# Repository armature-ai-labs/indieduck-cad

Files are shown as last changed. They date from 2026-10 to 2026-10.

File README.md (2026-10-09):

# IndieDuck by Armature AI Labs

A complete **R20 robot CAD study**, with the removable rear colour band integrated into the assembled robot. Adapted from Open Duck Mini and inspired by Pollen Robotics' MicroDuck, with reused XGO geometry identified in [THIRD_PARTY_NOTICES.md](THIRD_PARTY_NOTICES.md).

Armature's changes include compact joint supports, a two-eye face, local head-yaw clearance and a separately printable colour band. This repository contains the mechanical CAD only; runtime and reinforcement learning remain in [indieduck-runtime](https://github.com/armature-ai-labs/indieduck-runtime) and [indieduck-rl](https://github.com/armature-ai-labs/indieduck-rl).

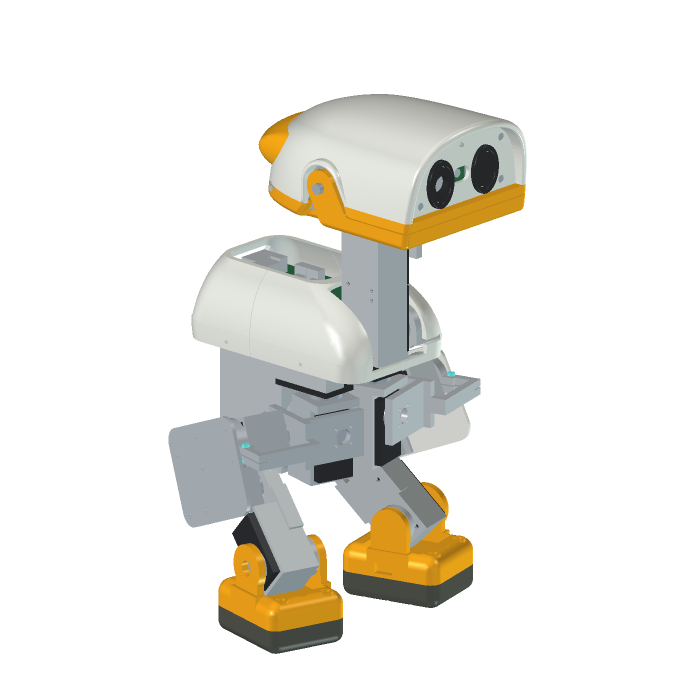
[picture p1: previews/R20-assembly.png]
R20 assembled CAD


## Explore and assemble

Open the [interactive R20 assembly guide](https://armature-ai-labs.github.io/indieduck/) for component selection, exploded views and assembly steps. The [R20 simulator](https://armature-ai-labs.github.io/indieduck-rl/) is a separate physics study. The guide uses the saved CAD assembly; it does not simulate a physical installation process.

The `assembly/` bundle provides revisioned, labelled display meshes and component records generated from this CAD. These are presentation assets, not additional printable parts. Use the native sources and `exports/` for mechanical editing and printing. Steps and hardware envelopes marked provisional require confirmation during the physical build.

## Open the robot

Download and extract the entire release ZIP, then open **`native/robot/IndieDuck_R20_Assembly.FCStd`** in FreeCAD 1.1.4. Keep these four sibling files together so relative links resolve:

| File | Purpose |
|---|---|
| `IndieDuck_R20_Assembly.FCStd` | Complete robot in its saved standing pose, including the mounted band |
| `IndieDuck_R20_Structure.FCStd` | Structural parts, covers, face, feet and retained construction history |
| `IndieDuck_R20_Interfaces.FCStd` | Joint carriers, clamps, retainers and hardware references |
| `IndieDuck_R20_HeadBand.FCStd` | Editable band profiles, attachment features and mounting-hole head shell |

Edit the source documents rather than presentation snapshots. Older feature names such as `R17_HeadPitch` remain stable identifiers inside R20; they do not indicate that an older assembly must be downloaded. Hidden construction objects are retained where they support editing and provenance. They are not additional parts to print.

The assembly's `YawMotion` spreadsheet accepts a plain number in cell B1, for example `-90`, `0` or `90`. This is a head-yaw study control, not a general pose editor or a guarantee of physical travel. Restore `0` for the default saved view.

## Files and colours

- `exports/`: matching R20 STEP and STL files for the 41 current printed-component candidates, plus the assembled STEP. Purchased servos, electronics, bearings and metal fasteners remain assembly references, not printed-component exports.
- `previews/`: actual assembled and inspection CAD views.
- `drawings/`: applicable review drawings. Inherited sheets retain their original revision labels; they are not a complete dimensioned manufacturing drawing set.
- [COMPONENTS.csv](COMPONENTS.csv) maps every current printed component; [MANIFEST.json](MANIFEST.json) and [SHA256SUMS](SHA256SUMS) identify the packaged files and their source objects. Keep native files and exports from the same release together.

Geometry uses **millimetres**. Individual exports retain their native CAD coordinates; they are not arranged on a build plate or sliced. Colour in the CAD is an appearance setting, not a material specification. Use PLA for initial rigid fit tests and TPU 95A for soles and lips. Bambu Studio can prepare printer-specific jobs after orientation, supports, nozzle and material profiles are checked.

Print the rear band separately in any desired colour. Multicolour printing is not required. The band covers the retained head reinforcement and is attached using two internal screws and captive nuts. Remove the head shell for screw access; the nuts load through the band's underside slots. It is tool-removable, not a snap-on accessory.

The **M2×10 screw with a nominal 0.5 mm washer** is a provisional stack, not a confirmed hardware specification. In the centre-line CAD stack it leaves about 0.492 mm screw-tip space; a bare 10 mm screw reaches the blind end. Confirm printed nut fit, screw length, head seating and tool access before tightening. The band is decorative, not a handle or impact bumper.

## Prototype limits

“Complete” means the current robot assembly and its current printed-component CAD are packaged together. CAD reopening, link checks, solid checks and export checks are distinct from physical fit, slicing, strength and motion tests. Read [VERIFICATION.md](VERIFICATION.md) for the exact checks performed on this release.

A band mesh/CAD volume discrepancy and a smaller assembled STEP volume discrepancy remain recorded in [VERIFICATION.md](VERIFICATION.md). Inherited neck-motion collisions remain unresolved. Combined head motion, cable routing, full band-removal travel, printed tolerances, bearing preload, fastener engagement and structural loads require further work. No trained walking, impact resistance or reproducible physical build is claimed by this release.

See [CONTRIBUTING.md](CONTRIBUTING.md) for changes. Source-specific attribution, applicable licences and unresolved redistribution terms are collected in [THIRD_PARTY_NOTICES.md](THIRD_PARTY_NOTICES.md); this mixed-source collection is not covered by a blanket Apache-2.0 grant.

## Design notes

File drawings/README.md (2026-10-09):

# Review drawings

The two PDF/SVG sheets in `inherited-R18/` document the compact neck and structural supports retained unchanged in R20. Their original revision labels are preserved. These are review drawings, not a full dimensioned manufacturing set. Use the R20 native model and component manifest for the current parts.

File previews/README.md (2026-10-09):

# Actual FreeCAD R20 views

Assembly, front, rear and attached-band views show the integrated R20 native assembly. `R20-band-exploded.png` temporarily translates only the band 35 mm rearward to reveal the retained shell reinforcement and mount holes. It illustrates separation, not a validated removal path. Geometry was restored after capture. Colours are appearance settings.

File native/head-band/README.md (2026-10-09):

# R20 removable colour band

The editable source is `../robot/IndieDuck_R20_HeadBand.FCStd`. It is kept beside the complete robot assembly so all external links use sibling paths. Edit `RemovableRearBand` and `HeadShellWithBandMounts` through their retained loft/profile/attachment features. Do not use the hidden construction features as additional printed parts.

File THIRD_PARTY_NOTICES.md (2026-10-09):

# Third-party notices and source attribution

IndieDuck by Armature AI Labs, adapted from Open Duck Mini and inspired by Pollen Robotics' MicroDuck.

Copyright 2026 Armature AI Labs for our engineering modifications. Our independently authored contributions and documentation are offered under Apache-2.0, whose text is included below. This grant does not extend to underlying third-party geometry or replace its source-specific terms. This R20 CAD study combines separately authored structure and interfaces, inherited geometry, and our changes. It is not covered by a single blanket Apache-2.0 grant. The retained upstream texts below apply to their respective material; public availability does not supply any missing upstream permission. No sponsorship, endorsement or trademark rights are asserted.

## Source scope

| Source | Pinned revision | Included or referenced material | Recorded terms |
| --- | --- | --- | --- |
| [Open Duck Mini](https://github.com/apirrone/Open_Duck_Mini) by Antoine Pirrone and contributors | `b23317a485b3cec7d8417f352478778b3475173c` | Retained native source history and adapted covers; Jaime Machuca's BD-X-style body-cover mod and Justin Andrews' Park Head mod are credited below. | Apache-2.0, text retained below. |
| [XGO-Duck hardware](https://github.com/LuwuDynamics/xgoduck_hardware) by Luwu Dynamics and upstream contributors | `8b355c6fc374ff7f2921bf78b4880c2b38c57b07` | Head shell, upper bill, jaw, upper/lower lips and retained support source geometry. R20 adds a separate band and shell mounting holes; earlier IndieDuck revisions changed the face, mounting, jaw support and yaw relief. | No finalized source-specific redistribution grant was established in the inspected snapshot. The snapshot's LICENSING and UPSTREAM texts are retained below. This geometry is not newly labelled Apache-2.0. |
| [MicroDuck / microduck_rl](https://github.com/pollen-robotics/microduck_rl) by Pollen Robotics | model reference `273afe0b31c4ab365b9ff806a927b63ac92b5ddd` | Robot inspiration and numerical joint, stance, foot and roller references. No original Pollen mesh files or policies are directly bundled. XGO's recorded Pollen lineage remains applicable to inherited XGO geometry. | Pinned repository distinguishes Apache-2.0 software from its model terms. Software permission is not asserted as a CAD grant. |
| Radxa ZERO 3W and Pollen RPI Robot HAT | Radxa V1.11 mechanical reference; HAT `78f60f711f519e8b57c4b1ea937bd2bb8249b1d3` | Numerical outline, mounting and component-envelope facts represented as reference shapes. | Original Radxa CAD and the HAT STEP's embedded Raspberry Pi model are not included. |
| Feetech HD-1910-C001 documentation | drawing/specification referenced in the project source register | Numerical servo interfaces and simplified hardware reference envelopes. | Manufacturer documentation is not relabelled as IndieDuck CAD. |

Armature contributions include the HD-1910 structure and interface features, compact joint supports, adapted covers, two-eye face and eye rings, foot studies, the upper-bill yaw clearance, and the removable rear band with internal mounting. An independently authored modification does not relicense underlying geometry. Hidden source features retained for editability are not an additional current print list.

For the active part-to-native-object mapping and material classification, use the package manifest. STEP/STL files inherit the provenance of their corresponding native objects. Assembly and review files combine those objects and do not broaden their permissions.

## Preserved contributor attribution

The following contributor README texts are reproduced verbatim from the pinned Open Duck Mini snapshot. Image links and references inside them describe the original upstream package, not files or verified print settings in this release.

### Jaime Machuca (jmachuca77)

```text
# Jaime's V2 BD‑X Style Body Covers Mod

![3D Model Overview](./3D%20Model.png)

Author: Jaime Machuca (jmachuca77)

## Purpose
This is an alternative set of v2 body/head cover parts for Open Duck Mini intended to more closely match the Disney BD‑X aesthetic and surface "skin" lines.

## Important Note on Balance & RL Policy
These covers shift the overall mass distribution and do not perfectly match the original center of gravity assumptions used when training the current reinforcement learning (RL) locomotion policy. The existing policy still works, but may exhibit slightly reduced stability (e.g. more wobble, occasional recovery steps). Monitor performance; if instability becomes an issue, consider fine‑tuning or retraining with updated inertial parameters.

## Printing Guidance
The file `Bambu_X1C_Project_File.3mf` contains suggested part orientations, plate groupings, and baseline settings optimized for a Bambu Labs X1C printer.

Recommended starting points (adjust to your material):
- Material: PETG or PLA-CF (for durability)
- Layer Height: 0.20 mm (features) / 0.28 mm (large flat shells optional)
- Infill: 15–20% gyroid or cubic
- Walls: 3 perimeters for strength on structural covers
- Supports: Only where unavoidable (check project file flags)
- Adhesion: Skirt or minimal brim for tall narrow pieces

![Print Orientation Reference](./Print%20Orientation%20Reference.png)

## Included Parts
Representative filenames (see folder for full list):
- Front/Back/Side body covers (`Front Cover.3mf`, `Back Panel.3mf`, `trunk_*`) 
- Leg covers and cable guides (`Left Leg Cover.3mf`, `Right Leg Cover.3mf`, upper/lower guides) 
- Greebles & panels (`Front Greeble.3mf`, `Front Panel V4.3mf`) 
- Safety / accessory plates (`E-Stop Panel.3mf`, `E-Stop Adapter Plate.3mf`) 
- Assembly helpers (`Hip Cable Holder.3mf`, `Top Body Support.3mf`)

## Usage & Attribution
Feel free to remix or adapt. Please retain attribution to Jaime Machuca (jmachuca77) and reference that this mod targets a closer Disney BD‑X visual style.

## Future Suggestions
- Retrain or fine‑tune RL policy with updated CAD mass properties.

---
If you encounter issues or improved orientations, open a PR or add notes here.
```

### Justin Andrews (Codezombie23)

```text
# Justin's Park Head Mod (BD‑X Style)

This mod updates the Open Duck Mini v2 head to more closely resemble the Disney BD‑X design.

![Park Head Mod Preview](./Park_Head.png)

- Author: Justin Andrews (Codezombie23)
- Project: Open Duck Mini v2 head mod

If you use or remix this, please credit the author above.
```

## Preserved XGO source notices

These are the inspected source snapshot texts. Their internal links refer to the upstream project; they are not an IndieDuck permission grant.

### XGO LICENSING.md

```text
# Licensing status

No top-level license file was found in the repository snapshot used for this documentation update. Publication of files by itself does not establish a complete reuse grant. Upstream and third-party components retain their applicable terms.

## Maintainer intent for eligible original material

The maintainer intends to allow personal and educational replication and require separate authorization for commercial use of material they have the right to license. This statement records intent; it is not a finalized replacement license and does not override any existing grants or third-party rights. File-level scope and final terms are pending.

A project-wide “noncommercial only” label would be inaccurate where Apache-2.0 or another license already permits commercial use. Noncommercial restrictions also do not meet the OSI definition of open-source software. Describe the actual license of each component rather than claiming the whole project is under one permissive license.

For a commercial enquiry, email **hello@xgorobot.com** with the files/revisions involved, intended product or service, expected quantity and distribution plans. For personal/educational replication of material without final terms, use the same address to confirm applicable permissions.

## Design and model provenance

Code licensing does not establish rights to every model or design asset. Review the upstream findings and file-level scope in the hardware repository's [origins documentation](https://github.com/LuwuDynamics/xgoduck_hardware) before distributing inherited designs. Exact source revisions and applicable notices remain to be recorded.

## Credits

The project builds on [Microduck](https://github.com/pollen-robotics/microduck) and [microduck_rl](https://github.com/pollen-robotics/microduck_rl) by Pollen Robotics. Training uses [mjlab](https://github.com/mujocolab/mjlab) and [BAM](https://github.com/Rhoban/bam). Hardware and software adaptations should be credited without implying endorsement by those projects or Arduino.

References: [OSI Open Source Definition](https://opensource.org/osd), [Apache-2.0 text](https://www.apache.org/licenses/LICENSE-2.0).
```

### XGO UPSTREAM.md

```text
# Origins and adaptations

[Project](readme.md) · [Licensing](LICENSING.md)

XGO-Duck is a substantial adaptation of the Microduck ecosystem, not an independently originated robot concept. The maintainer has confirmed extensive reference to Microduck materials. The XGO-Duck repository descriptions also identify that lineage. This page records the architectural relationship; it is not a completed file-by-file copyright audit.

## Credit the foundation

- [Microduck, Pollen Robotics](https://pollen-robotics.com/microduck/): the robot concept and upstream project.
- [Microduck runtime](https://github.com/pollen-robotics/microduck): upstream onboard software and system reference.
- [microduck_rl](https://github.com/pollen-robotics/microduck_rl): upstream learning environments and sim-to-real approach.
- [mjlab](https://github.com/mujocolab/mjlab): training framework.
- [BAM, Rhoban](https://github.com/Rhoban/bam): actuator modelling.

## What follows upstream and what is adapted

| Area | Inherited or referenced foundation | XGO-Duck adaptation documented in its source |
| --- | --- | --- |
| Robot form | Duck-shaped biped with articulated legs, neck, head and mouth | Printable XGO-Duck structure and assembly drawings |
| Joint layout | Fifteen servos and retained policy ordering | Feetech 1910 bus integration and per-robot encoder calibration |
| Learning | Microduck task recipes and PPO/ONNX workflow | XGO-Duck geometry/inertias and HLS1910 BAM parameters |
| Control interface | Shared policy conventions and motion concepts | Linux policy host plus STM32 control on Uno Q |
| Electronics | Reference robot architecture | Luwu expansion board with QMI8658A, power and servo interfaces |

“Adaptation” here describes the engineering work visible in the XGO-Duck source. It does not establish exclusive ownership of every file. The exact upstream base revision, copied paths, original design sources and permissions must still be recorded.

## Compatibility is a separate question

Use the XGO-Duck task IDs, dependencies and deployment instructions in these repositories. Do not substitute an upstream policy solely because its tensors have the same dimensions. Actuator dynamics, geometry, calibration, command meaning and runtime behavior must also agree.

Upstream commands such as `robotctl` belong to a different runtime. They are not XGO-Duck Uno Q installation instructions. Features demonstrated on an upstream robot are not evidence that this hardware variant supports them.

## Model and design rights need their own record

The current [upstream RL README](https://github.com/pollen-robotics/microduck_rl) distinguishes its code license from a noncommercial, share-alike statement for 3D models. Preserve the applicable terms for the actual inherited files and versions; obtain the precise license text and provenance before redistributing derivatives. A code LICENSE alone is insufficient evidence for model rights.

The official [Microduck press kit](https://pollen-robotics.com/microduck/press-kit/) also limits its open-source statement to software. Do not infer design-file permissions from product marketing. These observations were reviewed on 2026-09-26 and are not a finding that any specific XGO-Duck file is unauthorized.

## Attribution for articles and demonstrations

Suggested credit: **“XGO-Duck by Luwu Dynamics, based on Microduck and microduck_rl by Pollen Robotics.”** Add mjlab and Rhoban BAM when discussing training. Preserve file-level copyright and license notices in source distributions. This project does not claim endorsement by Pollen Robotics, Hugging Face, Rhoban or Arduino.
```

## Apache License 2.0 text for the Open Duck Mini material and separately designated Armature material

```text
                                 Apache License
                           Version 2.0, January 2004
                        http://www.apache.org/licenses/

   TERMS AND CONDITIONS FOR USE, REPRODUCTION, AND DISTRIBUTION

   1. Definitions.

      "License" shall mean the terms and conditions for use, reproduction,
      and distribution as defined by Sections 1 through 9 of this document.

      "Licensor" shall mean the copyright owner or entity authorized by
      the copyright owner that is granting the License.

      "Legal Entity" shall mean the union of the acting entity and all
      other entities that control, are controlled by, or are under common
      control with that entity. For the purposes of this definition,
      "control" means (i) the power, direct or indirect, to cause the
      direction or management of such entity, whether by contract or
      otherwise, or (ii) ownership of fifty percent (50%) or more of the
      outstanding shares, or (iii) beneficial ownership of such entity.

      "You" (or "Your") shall mean an individual or Legal Entity
      exercising permissions granted by this License.

      "Source" form shall mean the preferred form for making modifications,
      including but not limited to software source code, documentation
      source, and configuration files.

      "Object" form shall mean any form resulting from mechanical
      transformation or translation of a Source form, including but
      not limited to compiled object code, generated documentation,
      and conversions to other media types.

      "Work" shall mean the work of authorship, whether in Source or
      Object form, made available under the License, as indicated by a
      copyright notice that is included in or attached to the work
      (an example is provided in the Appendix below).

      "Derivative Works" shall mean any work, whether in Source or Object
      form, that is based on (or derived from) the Work and for which the
      editorial revisions, annotations, elaborations, or other modifications
      represent, as a whole, an original work of authorship. For the purposes
      of this License, Derivative Works shall not include works that remain
      separable from, or merely link (or bind by name) to the interfaces of,
      the Work and Derivative Works thereof.

      "Contribution" shall mean any work of authorship, including
      the original version of the Work and any modifications or additions
      to that Work or Derivative Works thereof, that is intentionally
      submitted to Licensor for inclusion in the Work by the copyright owner
      or by an individual or Legal Entity authorized to submit on behalf of
      the copyright owner. For the purposes of this definition, "submitted"
      means any form of electronic, verbal, or written communication sent
      to the Licensor or its representatives, including but not limited to
      communication on electronic mailing lists, source code control systems,
      and issue tracking systems that are managed by, or on behalf of, the
      Licensor for the purpose of discussing and improving the Work, but
      excluding communication that is conspicuously marked or otherwise
      designated in writing by the copyright owner as "Not a Contribution."

      "Contributor" shall mean Licensor and any individual or Legal Entity
      on behalf of whom a Contribution has been received by Licensor and
      subsequently incorporated within the Work.

   2. Grant of Copyright License. Subject to the terms and conditions of
      this License, each Contributor hereby grants to You a perpetual,
      worldwide, non-exclusive, no-charge, royalty-free, irrevocable
      copyright license to reproduce, prepare Derivative Works of,
      publicly display, publicly perform, sublicense, and distribute the
      Work and such Derivative Works in Source or Object form.

   3. Grant of Patent License. Subject to the terms and conditions of
      this License, each Contributor hereby grants to You a perpetual,
      worldwide, non-exclusive, no-charge, royalty-free, irrevocable
      (except as stated in this section) patent license to make, have made,
      use, offer to sell, sell, import, and otherwise transfer the Work,
      where such license applies only to those patent claims licensable
      by such Contributor that are necessarily infringed by their
      Contribution(s) alone or by combination of their Contribution(s)
      with the Work to which such Contribution(s) was submitted. If You
      institute patent litigation against any entity (including a
      cross-claim or counterclaim in a lawsuit) alleging that the Work
      or a Contribution incorporated within the Work constitutes direct
      or contributory patent infringement, then any patent licenses
      granted to You under this License for that Work shall terminate
      as of the date such litigation is filed.

   4. Redistribution. You may reproduce and distribute copies of the
      Work or Derivative Works thereof in any medium, with or without
      modifications, and in Source or Object form, provided that You
      meet the following conditions:

      (a) You must give any other recipients of the Work or
          Derivative Works a copy of this License; and

      (b) You must cause any modified files to carry prominent notices
          stating that You changed the files; and

      (c) You must retain, in the Source form of any Derivative Works
          that You distribute, all copyright, patent, trademark, and
          attribution notices from the Source form of the Work,
          excluding those notices that do not pertain to any part of
          the Derivative Works; and

      (d) If the Work includes a "NOTICE" text file as part of its
          distribution, then any Derivative Works that You distribute must
          include a readable copy of the attribution notices contained
          within such NOTICE file, excluding those notices that do not
          pertain to any part of the Derivative Works, in at least one
          of the following places: within a NOTICE text file distributed
          as part of the Derivative Works; within the Source form or
          documentation, if provided along with the Derivative Works; or,
          within a display generated by the Derivative Works, if and
          wherever such third-party notices normally appear. The contents
          of the NOTICE file are for informational purposes only and
          do not modify the License. You may add Your own attribution
          notices within Derivative Works that You distribute, alongside
          or as an addendum to the NOTICE text from the Work, provided
          that such additional attribution notices cannot be construed
          as modifying the License.

      You may add Your own copyright statement to Your modifications and
      may provide additional or different license terms and conditions
      for use, reproduction, or distribution of Your modifications, or
      for any such Derivative Works as a whole, provided Your use,
      reproduction, and distribution of the Work otherwise complies with
      the conditions stated in this License.

   5. Submission of Contributions. Unless You explicitly state otherwise,
      any Contribution intentionally submitted for inclusion in the Work
      by You to the Licensor shall be under the terms and conditions of
      this License, without any additional terms or conditions.
      Notwithstanding the above, nothing herein shall supersede or modify
      the terms of any separate license agreement you may have executed
      with Licensor regarding such Contributions.

   6. Trademarks. This License does not grant permission to use the trade
      names, trademarks, service marks, or product names of the Licensor,
      except as required for reasonable and customary use in describing the
      origin of the Work and reproducing the content of the NOTICE file.

   7. Disclaimer of Warranty. Unless required by applicable law or
      agreed to in writing, Licensor provides the Work (and each
      Contributor provides its Contributions) on an "AS IS" BASIS,
      WITHOUT WARRANTIES OR CONDITIONS OF ANY KIND, either express or
      implied, including, without limitation, any warranties or conditions
      of TITLE, NON-INFRINGEMENT, MERCHANTABILITY, or FITNESS FOR A
      PARTICULAR PURPOSE. You are solely responsible for determining the
      appropriateness of using or redistributing the Work and assume any
      risks associated with Your exercise of permissions under this License.

   8. Limitation of Liability. In no event and under no legal theory,
      whether in tort (including negligence), contract, or otherwise,
      unless required by applicable law (such as deliberate and grossly
      negligent acts) or agreed to in writing, shall any Contributor be
      liable to You for damages, including any direct, indirect, special,
      incidental, or consequential damages of any character arising as a
      result of this License or out of the use or inability to use the
      Work (including but not limited to damages for loss of goodwill,
      work stoppage, computer failure or malfunction, or any and all
      other commercial damages or losses), even if such Contributor
      has been advised of the possibility of such damages.

   9. Accepting Warranty or Additional Liability. While redistributing
      the Work or Derivative Works thereof, You may choose to offer,
      and charge a fee for, acceptance of support, warranty, indemnity,
      or other liability obligations and/or rights consistent with this
      License. However, in accepting such obligations, You may act only
      on Your own behalf and on Your sole responsibility, not on behalf
      of any other Contributor, and only if You agree to indemnify,
      defend, and hold each Contributor harmless for any liability
      incurred by, or claims asserted against, such Contributor by reason
      of your accepting any such warranty or additional liability.

   END OF TERMS AND CONDITIONS

   APPENDIX: How to apply the Apache License to your work.

      To apply the Apache License to your work, attach the following
      boilerplate notice, with the fields enclosed by brackets "[]"
      replaced with your own identifying information. (Don't include
      the brackets!)  The text should be enclosed in the appropriate
      comment syntax for the file format. We also recommend that a
      file or class name and description of purpose be included on the
      same "printed page" as the copyright notice for easier
      identification within third-party archives.

   Copyright [yyyy] [name of copyright owner]

   Licensed under the Apache License, Version 2.0 (the "License");
   you may not use this file except in compliance with the License.
   You may obtain a copy of the License at

       http://www.apache.org/licenses/LICENSE-2.0

   Unless required by applicable law or agreed to in writing, software
   distributed under the License is distributed on an "AS IS" BASIS,
   WITHOUT WARRANTIES OR CONDITIONS OF ANY KIND, either express or implied.
   See the License for the specific language governing permissions and
   limitations under the License.
```

## Native source mapping

The integrated R20 assembly preserves the R19 robot's datums and structural geometry, replaces the shell with its R20 mounting-hole variant, and adds the R20 removable band. R19 itself builds on R18 structural changes. Do not identify these inherited parts as newly redesigned in R20.

## Imported XGO geometry retained in the native history

Source repository: https://github.com/LuwuDynamics/xgoduck_hardware

Pinned revision: `8b355c6fc374ff7f2921bf78b4880c2b38c57b07`.

| Original file | Retained source object | Current role |
| --- | --- | --- |
| `head_shell.stl` | `XGO_HeadShell_Original`, `XGO_HeadShell_Aligned` | Basis of the modified shell; R20 mounted shell adds two screw holes. |
| `head.stl` | `XGO_head_Source` | Basis of the fastened upper bill and R19 yaw-relief feature. |
| `jaw.stl` | `XGO_jaw_Source` | Basis of the repaired active jaw. |
| `head_servo_support.stl` | `XGO_head_servo_support_Source` | Hidden retained history; superseded by the active IndieDuck cradles. |
| `mouth_up_tpu.stl` | `XGO_mouth_up_tpu_Source` | Active upper lip. |
| `mouth_buttom_tpu.stl` | `XGO_mouth_buttom_tpu_Source` | Active lower lip; source spelling retained. |

Those source STL shapes were converted into faceted B-reps, so editability does not mean every imported surface has an independent dimensioned feature history. Original IndieDuck feature trees, spreadsheets and Boolean modifications remain editable. The two-eye face follows the inherited head boundary and is a source-derived adapter. Native files retain hidden geometry needed for history; only active assembly objects belong in the current part list.

## Active printable classification

Initial rigid fit tests: PLA. Soft soles and lips: TPU 95A. Eye inserts are cosmetic aperture parts, not optical lenses; the camera lens and other bought hardware are reference geometry. All material choices remain prototype choices, not strength or print certification.

The active structural print set is the 39 visible non-reference R19 links preceding R18 hardware, plus the R18 neck-bearing retainer, with the shell replaced and the R20 removable band added: 41 physical printed-piece entries including left/right counterparts. The final component manifest records these 41 entries.

Exclude from printable-part exports: all `A_ref_*` items; hidden head-core/cap and crank-linkage alternatives; R18 bearing, idler, shoulder-pin, metal-spacer, screw and nut objects. Preserve their assembly reference shapes and distinguish any custom metal item still requiring manufacture or sourcing.

## Attribution scope

Open Duck Mini adapted source history includes Antoine Pirrone and contributors, Jaime Machuca's BD-X-style cover mod, and Justin Andrews' Park Head mod. Credit remains even when an older source feature is hidden. Pollen Robotics' MicroDuck supplies inspiration and numerical references. XGO's own source records Pollen lineage. Read THIRD_PARTY_NOTICES.md for the pinned records and preserved notices.

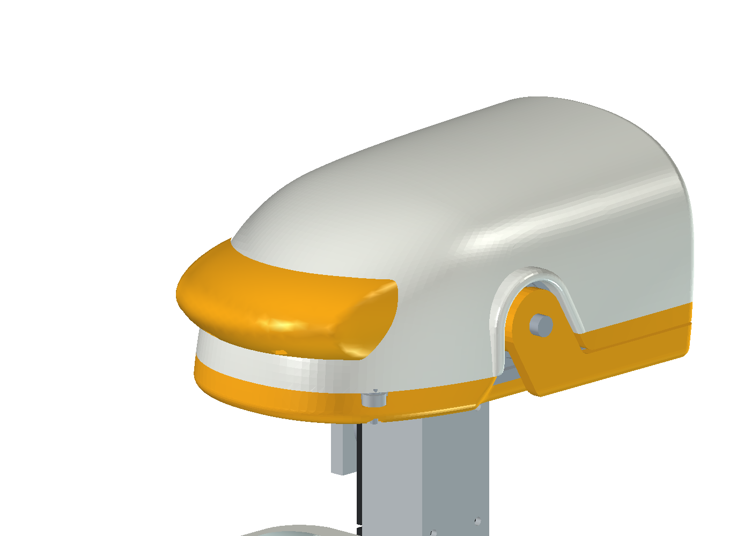
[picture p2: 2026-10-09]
previews/R20-head-band-attached.png

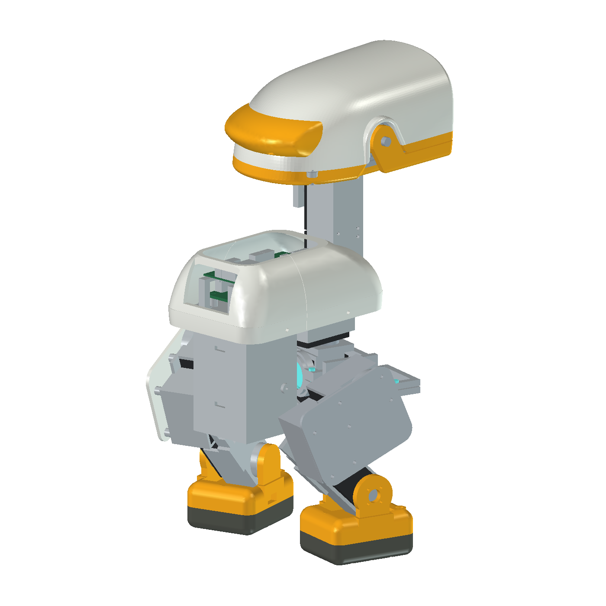
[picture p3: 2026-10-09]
previews/R20-rear.png

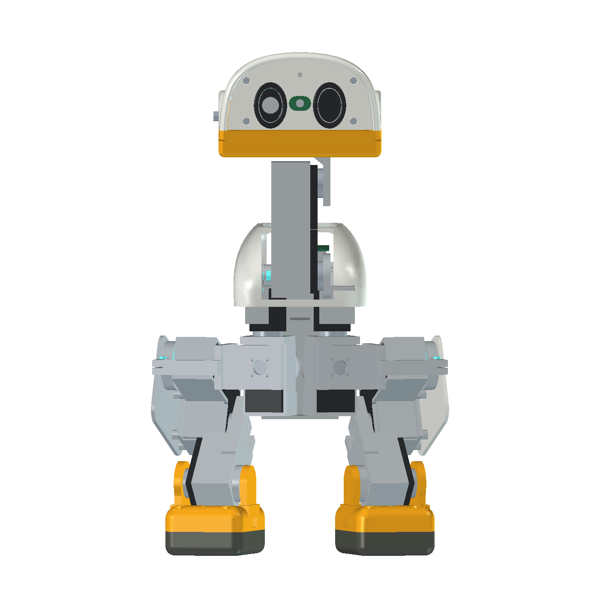
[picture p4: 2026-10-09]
previews/R20-front.png

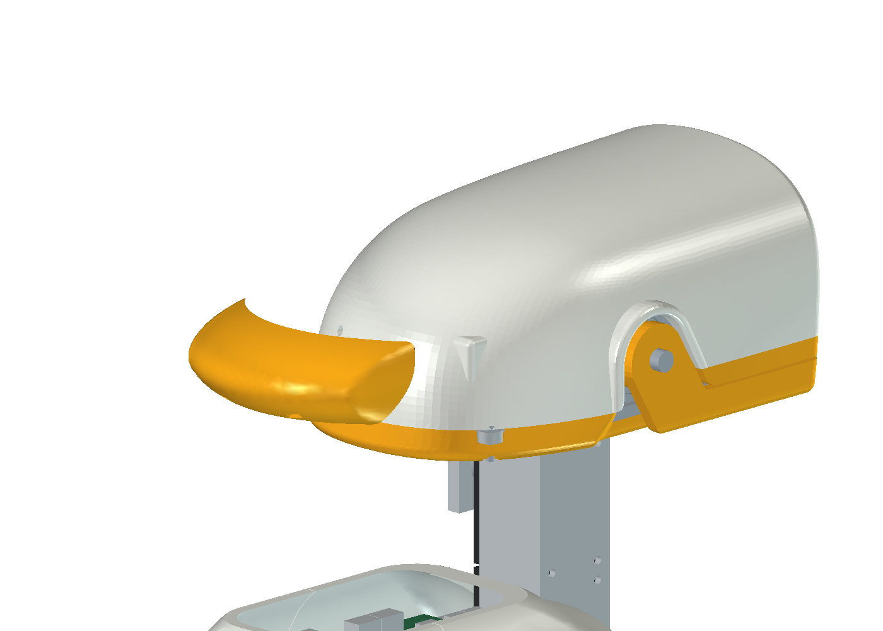
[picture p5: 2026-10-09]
previews/R20-band-exploded.png

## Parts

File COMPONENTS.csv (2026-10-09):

revision | assembly_link | native_file | native_object | material | step | stl | volume_mm3
R20 | A_Trunk | IndieDuck_R20_Structure.FCStd | Trunk | PLA initial fit test | exports/R20/step/R20_Trunk.step | exports/R20/stl/R20_Trunk.stl | 44277.92739148426
R20 | A_Neck | IndieDuck_R20_Structure.FCStd | Neck | PLA initial fit test | exports/R20/step/R20_Neck.step | exports/R20/stl/R20_Neck.stl | 10690.188350035962
R20 | A_HeadPitch | IndieDuck_R20_Interfaces.FCStd | R17_HeadPitch | PLA initial fit test | exports/R20/step/R20_HeadPitch.step | exports/R20/stl/R20_HeadPitch.stl | 4710.73565297739
R20 | A_HeadYaw | IndieDuck_R20_Interfaces.FCStd | R17_HeadYaw | PLA initial fit test | exports/R20/step/R20_HeadYaw.step | exports/R20/stl/R20_HeadYaw.stl | 11014.231494009247
R20 | A_Yaw_L | IndieDuck_R20_Structure.FCStd | Yaw_L | PLA initial fit test | exports/R20/step/R20_Yaw_L.step | exports/R20/stl/R20_Yaw_L.stl | 7221.906027288386
R20 | A_HipL_L | IndieDuck_R20_Structure.FCStd | HipL_L | PLA initial fit test | exports/R20/step/R20_HipL_L.step | exports/R20/stl/R20_HipL_L.stl | 11620.808308232043
R20 | A_Thigh_L | IndieDuck_R20_Structure.FCStd | Thigh_L | PLA initial fit test | exports/R20/step/R20_Thigh_L.step | exports/R20/stl/R20_Thigh_L.stl | 12356.28974082658
R20 | A_Shank_L | IndieDuck_R20_Structure.FCStd | Shank_L | PLA initial fit test | exports/R20/step/R20_Shank_L.step | exports/R20/stl/R20_Shank_L.stl | 10245.797471616492
R20 | A_RoundedFoot_L | IndieDuck_R20_Structure.FCStd | R11_CompactFoot_L | PLA initial fit test | exports/R20/step/R20_RoundedFoot_L.step | exports/R20/stl/R20_RoundedFoot_L.stl | 28315.681046755963
R20 | A_SoftHeadShell | IndieDuck_R20_HeadBand.FCStd | HeadShellWithBandMounts | PLA initial fit test | exports/R20/step/R20_SoftHeadShell.step | exports/R20/stl/R20_SoftHeadShell.stl | 34997.971631238855
R20 | A_BodyFront | IndieDuck_R20_Structure.FCStd | R08_BodyFront | PLA initial fit test | exports/R20/step/R20_BodyFront.step | exports/R20/stl/R20_BodyFront.stl | 17587.183555588643
R20 | A_BodyBack | IndieDuck_R20_Structure.FCStd | R08_BodyBack | PLA initial fit test | exports/R20/step/R20_BodyBack.step | exports/R20/stl/R20_BodyBack.stl | 13710.578381597243
R20 | A_RoundedSole_L | IndieDuck_R20_Structure.FCStd | R11_CompactSole_L | TPU 95A | exports/R20/step/R20_RoundedSole_L.step | exports/R20/stl/R20_RoundedSole_L.stl | 29010.262001846408
R20 | A_ThighPlate_L | IndieDuck_R20_Structure.FCStd | ThighPlate_L | PLA initial fit test | exports/R20/step/R20_ThighPlate_L.step | exports/R20/stl/R20_ThighPlate_L.stl | 6231.957271678276
R20 | A_O2_HeadBase | IndieDuck_R20_Structure.FCStd | R19_UpperBillYawClearance | PLA initial fit test | exports/R20/step/R20_O2_HeadBase.step | exports/R20/stl/R20_O2_HeadBase.stl | 31372.91213574358
R20 | A_O2_Jaw | IndieDuck_R20_Structure.FCStd | R17_RepairedJaw | PLA initial fit test | exports/R20/step/R20_O2_Jaw.step | exports/R20/stl/R20_O2_Jaw.stl | 15146.492824678711
R20 | A_O2_UpperLip | IndieDuck_R20_Structure.FCStd | XGO_mouth_up_tpu_Source | TPU 95A | exports/R20/step/R20_O2_UpperLip.step | exports/R20/stl/R20_O2_UpperLip.stl | 3571.5854312028546
R20 | A_O2_JawEdge | IndieDuck_R20_Structure.FCStd | XGO_mouth_buttom_tpu_Source | TPU 95A | exports/R20/step/R20_O2_JawEdge.step | exports/R20/stl/R20_O2_JawEdge.stl | 13826.479807112106
R20 | A_Yaw_R | IndieDuck_R20_Structure.FCStd | Yaw_R | PLA initial fit test | exports/R20/step/R20_Yaw_R.step | exports/R20/stl/R20_Yaw_R.stl | 7221.906027288384
R20 | A_HipL_R | IndieDuck_R20_Structure.FCStd | HipL_R | PLA initial fit test | exports/R20/step/R20_HipL_R.step | exports/R20/stl/R20_HipL_R.stl | 11620.808308232014
R20 | A_Thigh_R | IndieDuck_R20_Structure.FCStd | Thigh_R | PLA initial fit test | exports/R20/step/R20_Thigh_R.step | exports/R20/stl/R20_Thigh_R.stl | 12356.289740826596
R20 | A_Shank_R | IndieDuck_R20_Structure.FCStd | Shank_R | PLA initial fit test | exports/R20/step/R20_Shank_R.step | exports/R20/stl/R20_Shank_R.stl | 10245.797471616492
R20 | A_RoundedFoot_R | IndieDuck_R20_Structure.FCStd | R11_CompactFoot_R | PLA initial fit test | exports/R20/step/R20_RoundedFoot_R.step | exports/R20/stl/R20_RoundedFoot_R.stl | 28315.681046755963
R20 | A_RoundedSole_R | IndieDuck_R20_Structure.FCStd | R11_CompactSole_R | TPU 95A | exports/R20/step/R20_RoundedSole_R.step | exports/R20/stl/R20_RoundedSole_R.stl | 29010.262001846408
R20 | A_ThighPlate_R | IndieDuck_R20_Structure.FCStd | ThighPlate_R | PLA initial fit test | exports/R20/step/R20_ThighPlate_R.step | exports/R20/stl/R20_ThighPlate_R.stl | 6231.957271678276
R20 | A_O2_EyeL | IndieDuck_R20_Structure.FCStd | O2_EyeL | PLA initial fit test | exports/R20/step/R20_O2_EyeL.step | exports/R20/stl/R20_O2_EyeL.stl | 648.613219260149
R20 | A_O2_EyeR | IndieDuck_R20_Structure.FCStd | O2_EyeR | PLA initial fit test | exports/R20/step/R20_O2_EyeR.step | exports/R20/stl/R20_O2_EyeR.stl | 402.6516472252967
R20 | A_R10_EyeRing_L | IndieDuck_R20_Structure.FCStd | R10_EyeRing_L | PLA initial fit test | exports/R20/step/R20_R10_EyeRing_L.step | exports/R20/stl/R20_R10_EyeRing_L.stl | 366.29085157216963
R20 | A_R10_EyeRing_R | IndieDuck_R20_Structure.FCStd | R10_EyeRing_R | PLA initial fit test | exports/R20/step/R20_R10_EyeRing_R.step | exports/R20/stl/R20_R10_EyeRing_R.stl | 366.29085157214286
R20 | A_R16_TwoEyeFace | IndieDuck_R20_Structure.FCStd | R17_FastenedFace | PLA initial fit test | exports/R20/step/R20_R16_TwoEyeFace.step | exports/R20/stl/R20_R16_TwoEyeFace.stl | 4539.988175798913
R20 | A_R17_HeadYawClampCap | IndieDuck_R20_Interfaces.FCStd | R17_HeadYawClampCap | PLA initial fit test | exports/R20/step/R20_R17_HeadYawClampCap.step | exports/R20/stl/R20_R17_HeadYawClampCap.stl | 2735.7781483846798
R20 | A_R17_RollServoCradle | IndieDuck_R20_Interfaces.FCStd | R17_RollServoCradleV2 | PLA initial fit test | exports/R20/step/R20_R17_RollServoCradle.step | exports/R20/stl/R20_R17_RollServoCradle.stl | 4171.938268164332
R20 | A_R17_RollCradleTopClamp | IndieDuck_R20_Interfaces.FCStd | R17_RollCradleTopClamp | PLA initial fit test | exports/R20/step/R20_R17_RollCradleTopClamp.step | exports/R20/stl/R20_R17_RollCradleTopClamp.stl | 585.5904057892811
R20 | A_R17_MouthServoCradle | IndieDuck_R20_Interfaces.FCStd | R17_MouthServoCradle | PLA initial fit test | exports/R20/step/R20_R17_MouthServoCradle.step | exports/R20/stl/R20_R17_MouthServoCradle.stl | 4577.959993462735
R20 | A_R17_MouthServoKeeper | IndieDuck_R20_Interfaces.FCStd | R17_MouthServoKeeper | PLA initial fit test | exports/R20/step/R20_R17_MouthServoKeeper.step | exports/R20/stl/R20_R17_MouthServoKeeper.stl | 428.39035496132556
R20 | A_R17_JawBearingTower | IndieDuck_R20_Interfaces.FCStd | TowerFootMount1 | PLA initial fit test | exports/R20/step/R20_R17_JawBearingTower.step | exports/R20/stl/R20_R17_JawBearingTower.stl | 2244.0511096061323
R20 | A_R17_JawBearingKeeper | IndieDuck_R20_Interfaces.FCStd | KeeperClearance1 | PLA initial fit test | exports/R20/step/R20_R17_JawBearingKeeper.step | exports/R20/stl/R20_R17_JawBearingKeeper.stl | 579.6925364195824
R20 | A_R17_JawBearingPlug | IndieDuck_R20_Interfaces.FCStd | PlugNutPocket | PLA initial fit test | exports/R20/step/R20_R17_JawBearingPlug.step | exports/R20/stl/R20_R17_JawBearingPlug.stl | 1125.0967661892291
R20 | A_R17_FaceCarrier | IndieDuck_R20_Interfaces.FCStd | R17Face_Carrier_80 | PLA initial fit test | exports/R20/step/R20_R17_FaceCarrier.step | exports/R20/stl/R20_R17_FaceCarrier.stl | 3018.411385927126
R20 | A_R18_NeckBearingRetainer | IndieDuck_R20_Interfaces.FCStd | R18_NeckBearingRetainer | PLA initial fit test | exports/R20/step/R20_R18_NeckBearingRetainer.step | exports/R20/stl/R20_R18_NeckBearingRetainer.stl | 406.7385185212833
R20 | A_R20_RemovableRearBand | IndieDuck_R20_HeadBand.FCStd | RemovableRearBand | PLA initial fit test | exports/R20/step/R20_R20_RemovableRearBand.step | exports/R20/stl/R20_R20_RemovableRearBand.stl | 7729.233772642257

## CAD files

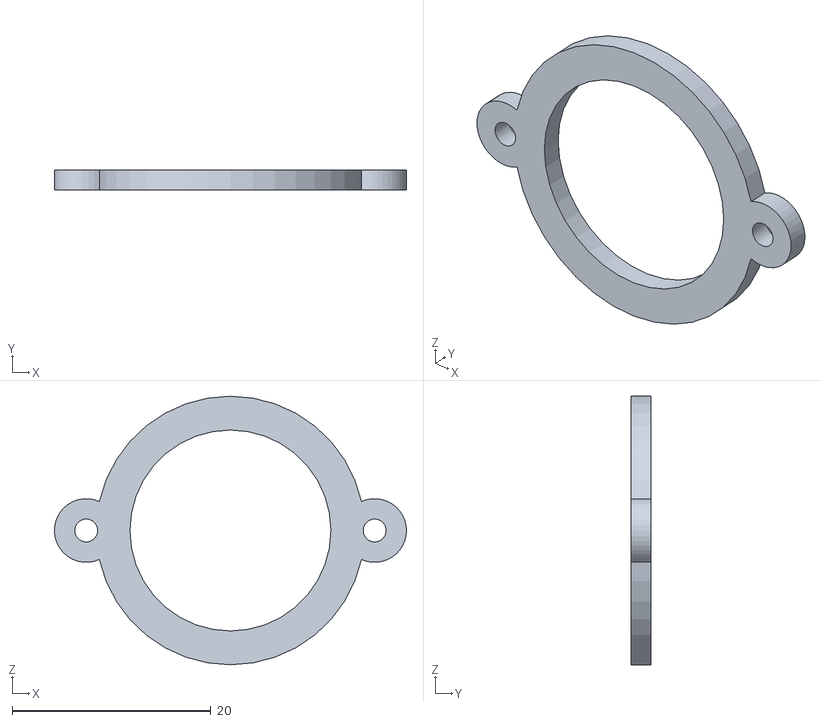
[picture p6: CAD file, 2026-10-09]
assembly/meshes/A_R17_JawBearingKeeper.stl
35.4 x 2.00 x 27.0

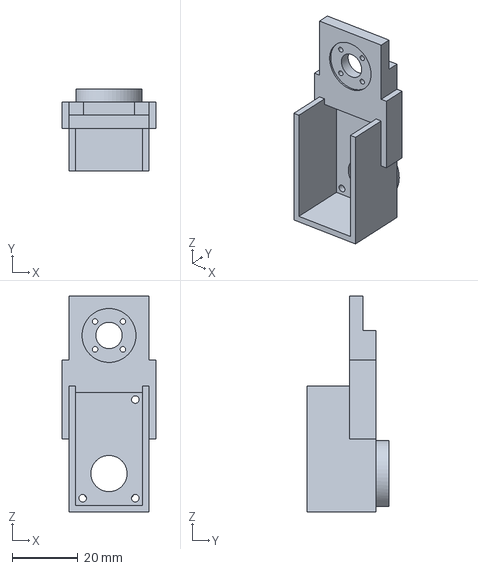
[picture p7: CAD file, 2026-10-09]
exports/R20/step/R20_Shank_R.step
28.5 x 25.0 x 65.7 mm

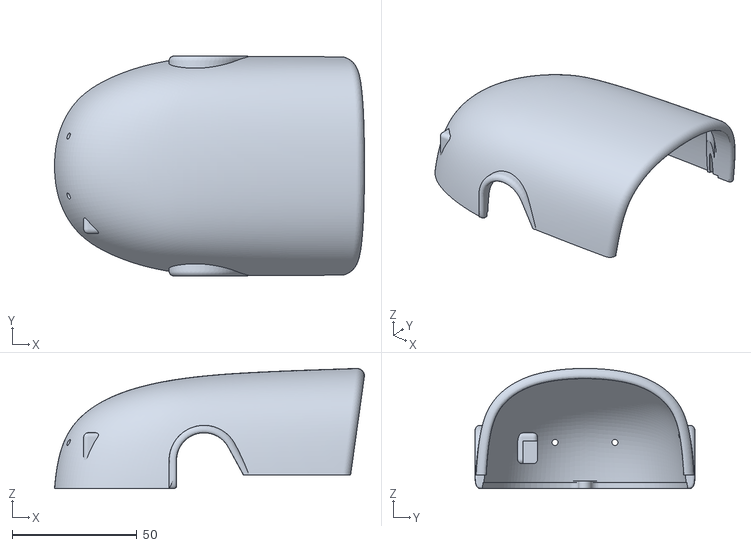
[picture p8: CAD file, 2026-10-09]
exports/R20/stl/R20_SoftHeadShell.stl
124.1 x 88.0 x 48.1

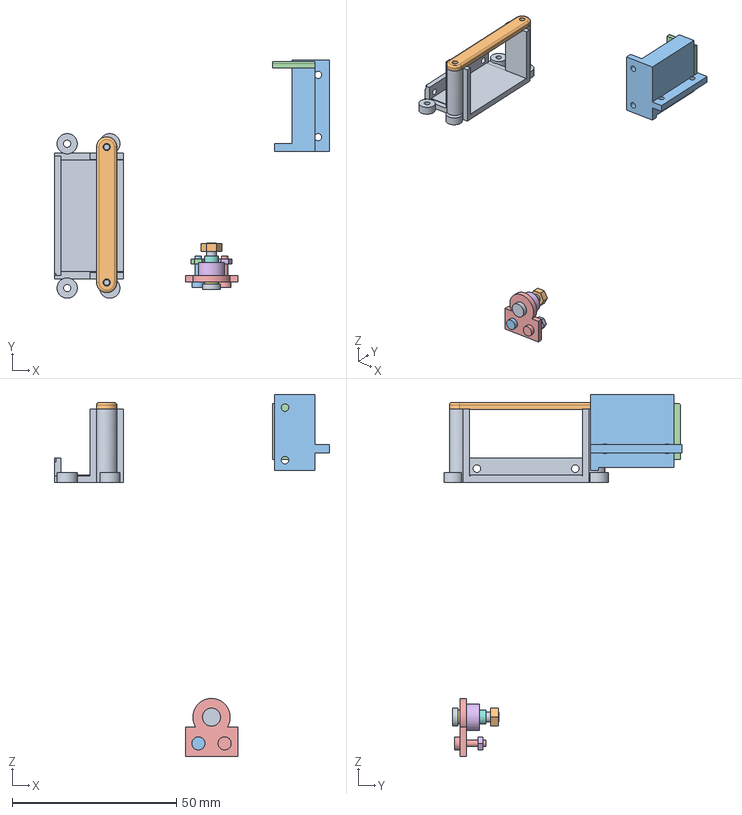
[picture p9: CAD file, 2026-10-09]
native/robot/IndieDuck_R20_Interfaces.FCStd
83.9 x 72.7 x 110.3 mm
R17_RollServoCradleV2
R17_RollCradleTopClamp
R17_MouthServoCradle
R17_MouthServoKeeper
R18_NeckBearingRetainer
R18_NeckBearing693
R18_NeckSpacerOuter
R18_NeckSpacerInner
R18_NeckShoulderPin
R18_NeckM3Nut
R18_NeckRetainerM2Screw0
R18_NeckRetainerM2Nut0
R18_NeckRetainerM2Screw1
R18_NeckRetainerM2Nut1

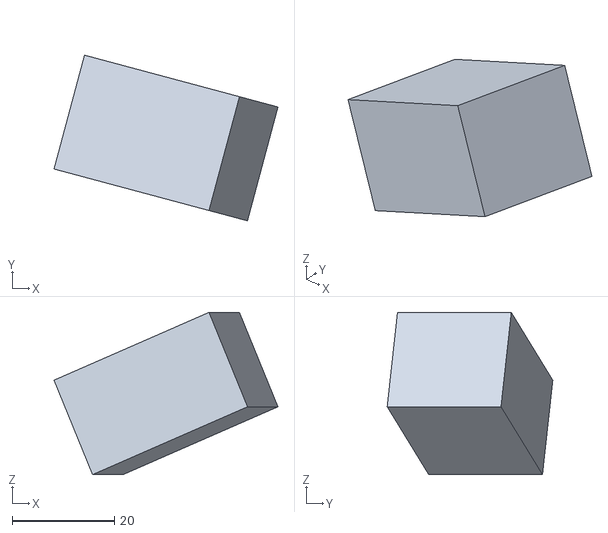
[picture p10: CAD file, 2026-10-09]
assembly/meshes/A_ref_servo_right_hip_pitch.stl
43.7 x 32.3 x 31.7

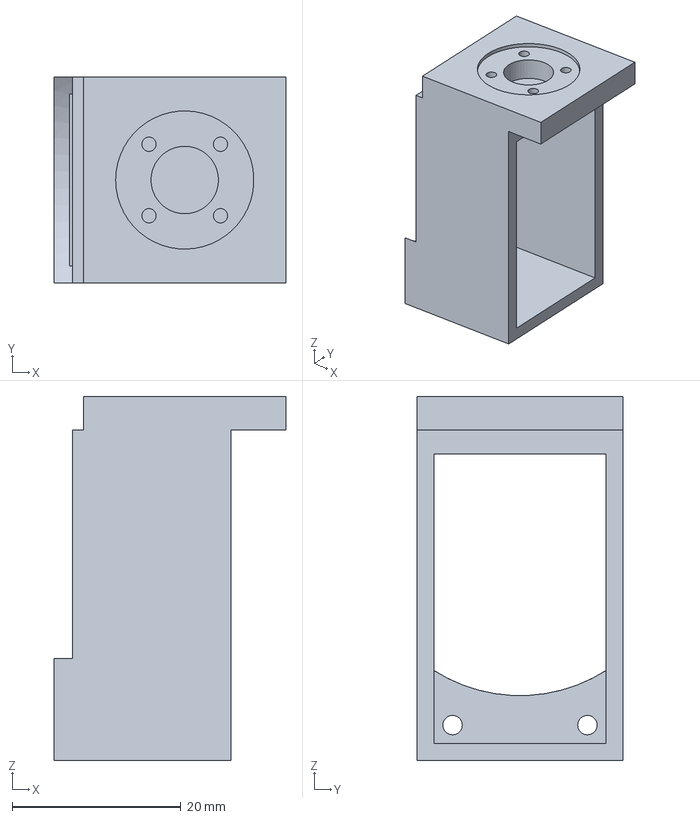
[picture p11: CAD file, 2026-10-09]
exports/R20/step/R20_Yaw_R.step
27.5 x 24.4 x 43.2 mm

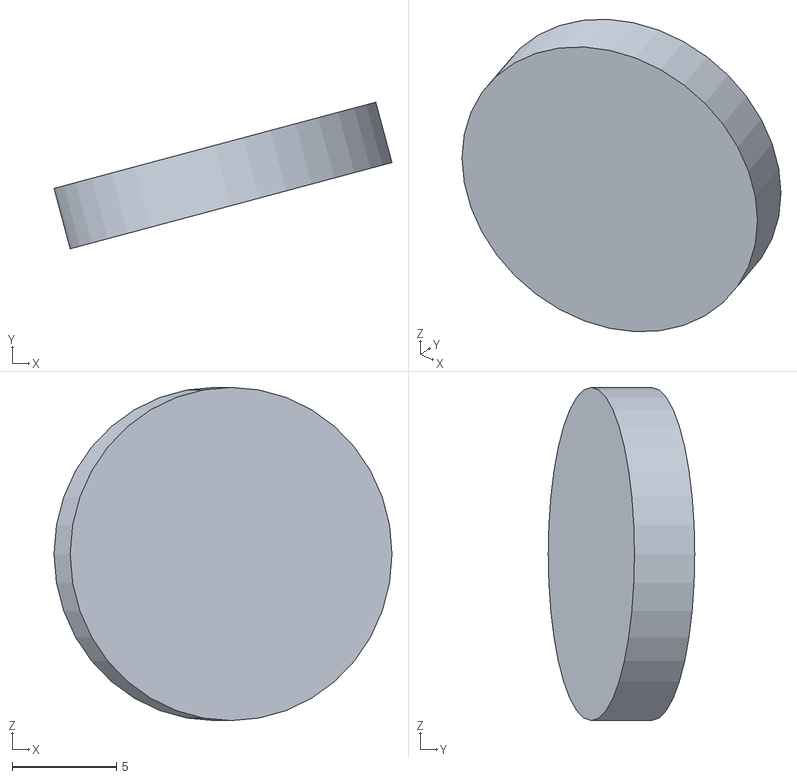
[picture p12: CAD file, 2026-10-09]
assembly/meshes/A_ref_horn_left_hip_pitch.stl
16.2 x 7.04 x 16.0

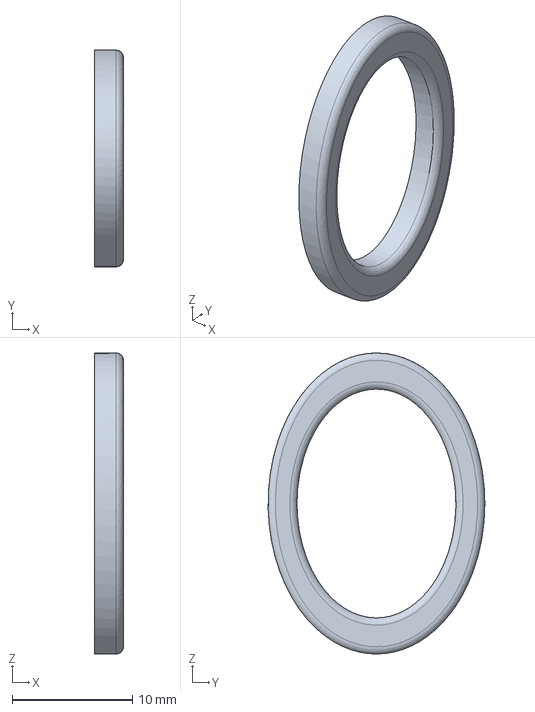
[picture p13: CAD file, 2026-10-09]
exports/R20/step/R20_R10_EyeRing_R.step
2.40 x 18.0 x 25.0 mm

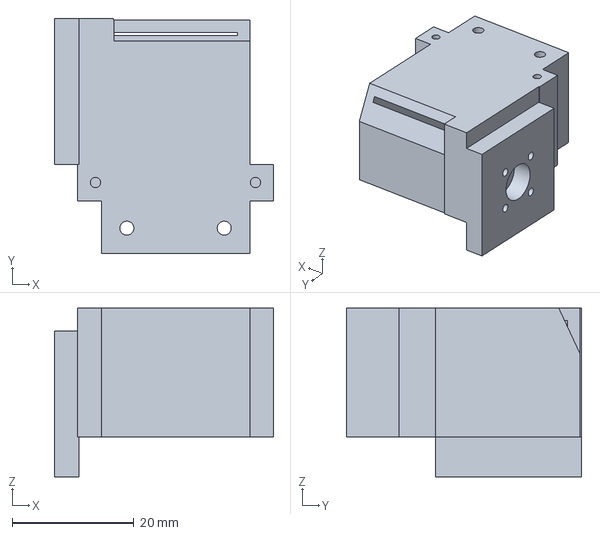
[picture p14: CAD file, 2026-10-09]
exports/R20/step/R20_HeadYaw.step
36.0 x 38.7 x 27.7 mm

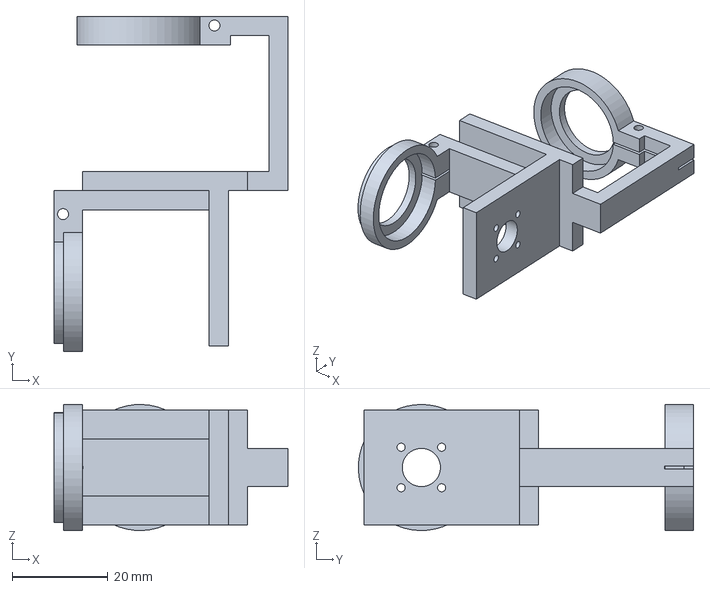
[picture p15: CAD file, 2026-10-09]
exports/R20/step/R20_HipL_L.step
49.0 x 70.2 x 26.4 mm

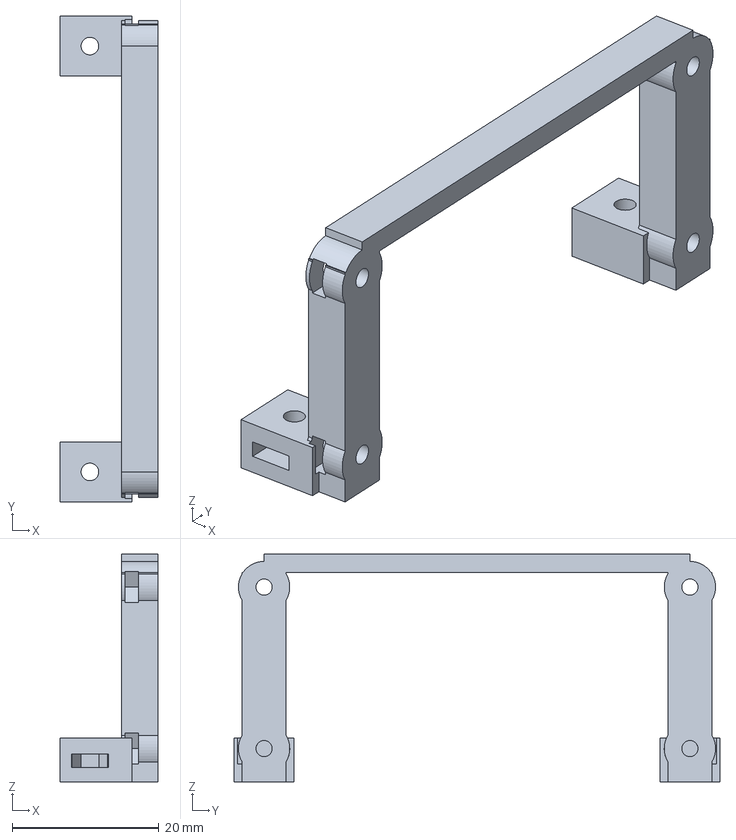
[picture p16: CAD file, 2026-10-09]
exports/R20/step/R20_R17_FaceCarrier.step
13.4 x 66.2 x 31.0 mm

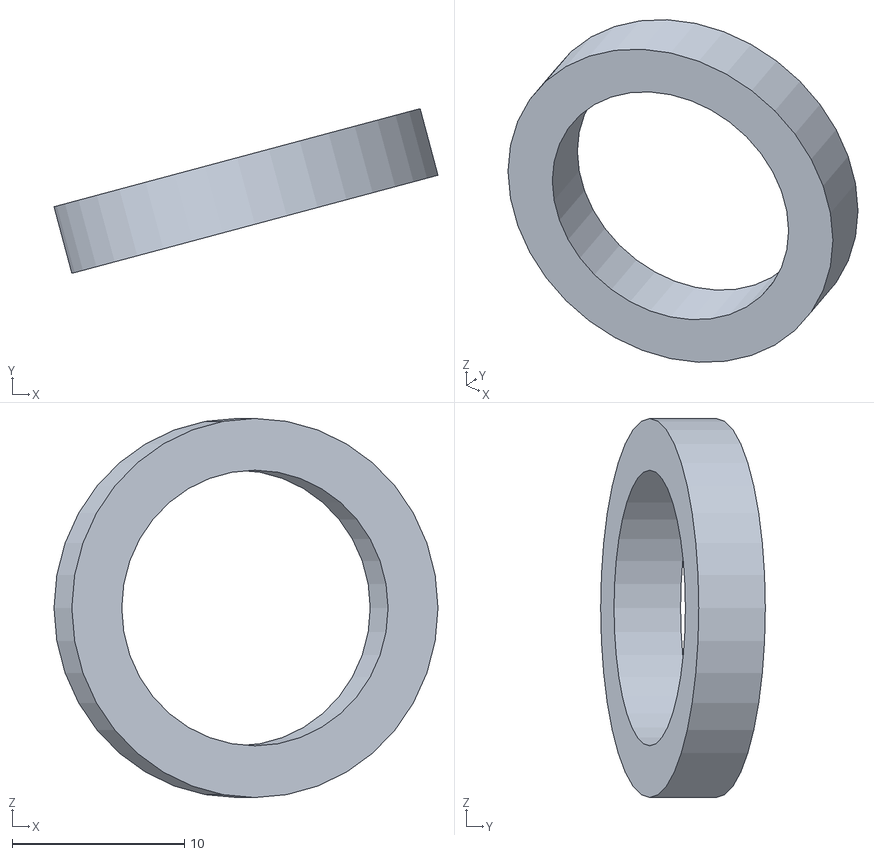
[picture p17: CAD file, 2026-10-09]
assembly/meshes/A_R18C_PitchBearing_L.stl
22.3 x 9.56 x 22.0

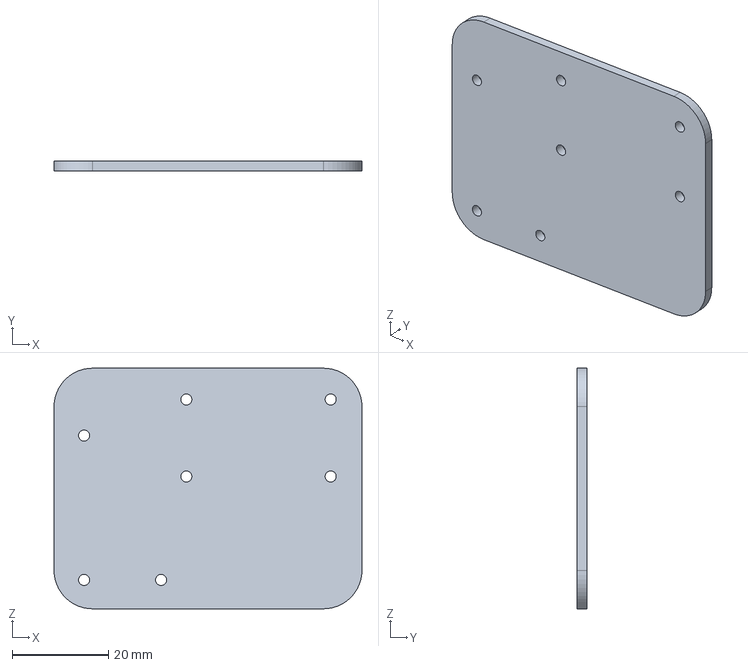
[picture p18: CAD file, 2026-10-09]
exports/R20/step/R20_ThighPlate_R.step
64.0 x 2.00 x 50.0 mm

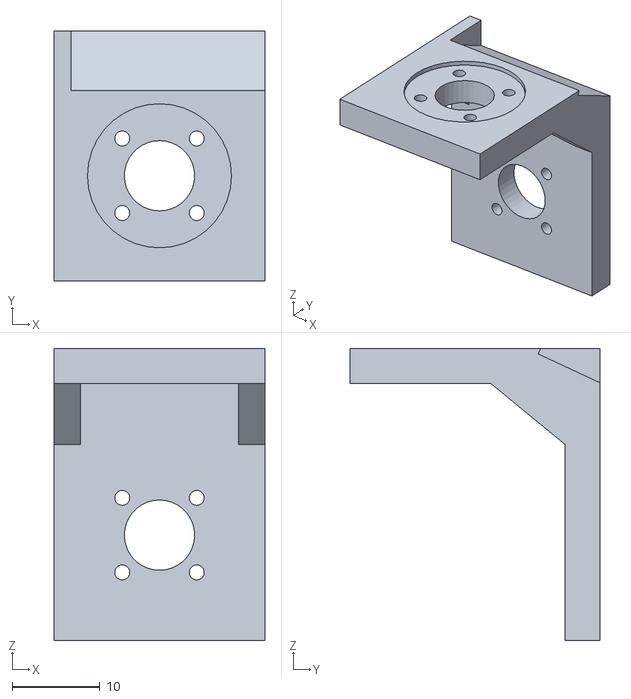
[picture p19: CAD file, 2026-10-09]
assembly/meshes/A_HeadPitch.stl
24.0 x 28.5 x 33.2

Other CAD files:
native/robot/IndieDuck_R20_Assembly.FCStd
assembly/meshes/A_R18C_PitchIdler_R.stl
assembly/meshes/A_ref_horn_left_hip_roll.stl
exports/R20/step/R20_Trunk.step
assembly/meshes/A_BodyBack.stl
assembly/meshes/A_BodyFront.stl
assembly/meshes/A_HeadYaw.stl
assembly/meshes/A_HipL_L.stl
assembly/meshes/A_HipL_R.stl
assembly/meshes/A_Neck.stl
assembly/meshes/A_O2_EyeL.stl
assembly/meshes/A_O2_EyeR.stl
assembly/meshes/A_O2_HeadBase.stl
assembly/meshes/A_O2_Jaw.stl
assembly/meshes/A_O2_JawEdge.stl
assembly/meshes/A_O2_UpperLip.stl
assembly/meshes/A_R10_EyeRing_L.stl
assembly/meshes/A_R10_EyeRing_R.stl
assembly/meshes/A_R16_TwoEyeFace.stl
assembly/meshes/A_R17_FaceCarrier.stl
assembly/meshes/A_R17_HeadYawClampCap.stl
assembly/meshes/A_R17_JawBearingPlug.stl
assembly/meshes/A_R17_JawBearingTower.stl
assembly/meshes/A_R17_MouthServoCradle.stl
assembly/meshes/A_R17_MouthServoKeeper.stl
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

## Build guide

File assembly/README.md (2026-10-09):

# R20 CAD assembly display assets

Generated from the complete native R20 assembly at CAD commit `7bcdd1696516f9cff6bdefbc34e42f259c87749a`. The browser guide source lives in [indieduck](https://github.com/armature-ai-labs/indieduck/tree/main/assembly-guide).

`manifest.json` identifies 124 visible CAD component references, including 41 current printed components. Some hardware references are compound shapes, so 124 is not a physical procurement quantity. Meshes retain assembled CAD coordinates in millimetres: X forward, Y left, Z up, with the R12 natural standing pose. No mesh is centred independently.

These lightweight presentation meshes total 128,318 triangles. Their 0.15 mm linear / 0.35 rad angular tessellation settings differ from the manufacturing exports. Do not print this directory. Use `exports/R20/` and the native sources for mechanical work. Per-mesh SHA-256 values are in the manifest.

Colours describe saved CAD appearance, not measured material properties. Purchased references and unresolved dimensions remain provisional. Source-specific terms in [THIRD_PARTY_NOTICES.md](../THIRD_PARTY_NOTICES.md) apply to these derivatives too.

Regeneration uses `tools/export_r20_cad.py` in the matching [RL release](https://github.com/armature-ai-labs/indieduck-rl/releases/tag/r20-simulation-study-v1), under FreeCAD with NumPy available. Set `INDIEDUCK_CAD` to this repository and `INDIEDUCK_ASSETS` to a separate output directory. The script reads native geometry without saving changes. Its explicit component/body mapping fails if a component is unmapped.

The browser guide adds separately labelled provisional assembly markers. Those are not native CAD additions and must not be mistaken for verified hardware.

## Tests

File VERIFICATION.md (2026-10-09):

# R20 CAD verification

This release combines the complete saved robot assembly and 41 current printed-component candidates in one R20 CAD package. Verification concerns this digital package. It does not establish a physically buildable or motion-qualified robot.

## Recorded checks

| Check | Evidence and scope |
|---|---|
| Isolated native reopening | PASS in the recorded copied-folder check. The original project was inaccessible. All dependencies resolved within the four packaged sibling FreeCAD documents. The assembly contained 135 links, with 124 visible. |
| Active geometry | The isolated check reported no active-shape failures. Native construction history remains present, including 29 thigh features, 17 neck features, 20 head-pitch base features and 29 band profile sections. Presence of that history is not a full parameter-change/recompute certification. |
| Head-yaw control | The assembled band followed the yaw group at -90°, 0° and +90°. Recorded point errors were below 0.000001 mm. This tests the CAD transform, not servo travel or cable freedom. |
| Added-band clearance | Exact overlap was 0 mm³ against the modified shell, head-roll servo reference, roll cradle and head-module fastener references. For pure vertical yaw at the tested base pose, invariant Z bounds separated the band from all 87 fixed parts by at least 9.2135 mm. This does not certify combined pitch/roll movement or removal travel. |
| STEP exports | All 41 individual STEP exports reopened as valid single solids. Maximum recorded volume drift from native geometry was 7.937 ppm. The assembled STEP used 124 visible assembly objects. |
| Initial STL export generation | The export-generation record reports closed meshes for all 41 parts. Independent saved-file readback and mesh precision are reported separately below. |

The new band checks supplement the inherited R19 rigid pure-yaw work. They do not extend that work to combined-joint trajectories, cable deformation or physical hardware.

## Saved-file and display checks

- All 41 saved STLs reopened as closed meshes. Forty had volume differences below 2% against the native CAD. The band's refined 49,552-facet STL is closed, consistently oriented, manifold and has no detected self-intersections. Its volume still differs by approximately 2.26% from the BRep value. Finer tessellation did not remove this discrepancy; its cause remains unresolved. This is not a band precision pass.
- The complete STEP reopens as a valid shape. Its volume differs by approximately 0.05275% from the sum of visible native shapes, above the initial 100 ppm comparison threshold. This numerical discrepancy is retained in `validation/export-readback.json`; no mass-property equivalence is claimed.
- A separate GUI reopen confirmed both leg structures, attached band and retained colours. Hidden Body final features were restored in the staged copies. Colours are stored on source parts to survive link reopening. Temporary diagnostic shapes were removed.
- `MANIFEST.json` records revision, role, size and SHA-256 for the packaged payload; `SHA256SUMS` also covers that manifest. Neither checksum file claims to hash itself.
- Post-publication anonymous download and reopen results are recorded in the release's separate verification asset. Keeping that receipt outside the ZIP avoids changing the archive after verification.

## Physical and manufacturing limits

No new slicing or printer job is included. STL files are in millimetres in their native CAD frames, without approved print orientation, support settings or printer-specific profiles. Initial rigid fit-test material is PLA; soles and lips are TPU 95A.

Inherited neck-motion collisions remain unresolved. Physical fit, structural strength, impact resistance, bearing preload, fastener engagement, continuous combined-joint motion, gait and dynamic cable routing are unverified. Drawings in this package are bounded review sheets, not a complete manufacturing drawing set.

The band's two screws, washers and captive nuts are not explicitly modelled in the assembly. Their provisional candidate is M2×10 with a nominal 0.5 mm washer, leaving approximately 0.492 mm screw-tip space in the centre-line CAD stack. Without the washer, the nominal screw reaches the blind end. Actual nut dimensions, printed fit, screw-head seating, screw length and driver access require a fit test. Shell removal is required for access, and full band-removal travel remains unchecked.

Source identity and licence status are recorded separately in [THIRD_PARTY_NOTICES.md](THIRD_PARTY_NOTICES.md). Geometry checks do not resolve source rights.

## R20 browser assembly bundle, 09-10-2026

Added 124 CAD display-reference meshes, including the same 41 printable candidates, with assembled coordinates and source identities. All mesh checksums match their generated manifest. The display bundle has 128,318 triangles and is not a manufacturing export. The original four native documents and 41 print STEP/STL pairs are unchanged from `cad-study-2026-10-09`.

Additional band screw, washer and nut records are labelled provisional presentation envelopes, separate from the 124 native references. They express the recorded two mounting axes and candidate stack; no manufacturer geometry, physical fastener fit or insertion clearance is certified.

The Three.js guide and physics simulator are separate tools. Browser assembly separation does not validate continuous insertion paths, structural loads or wired joint travel.

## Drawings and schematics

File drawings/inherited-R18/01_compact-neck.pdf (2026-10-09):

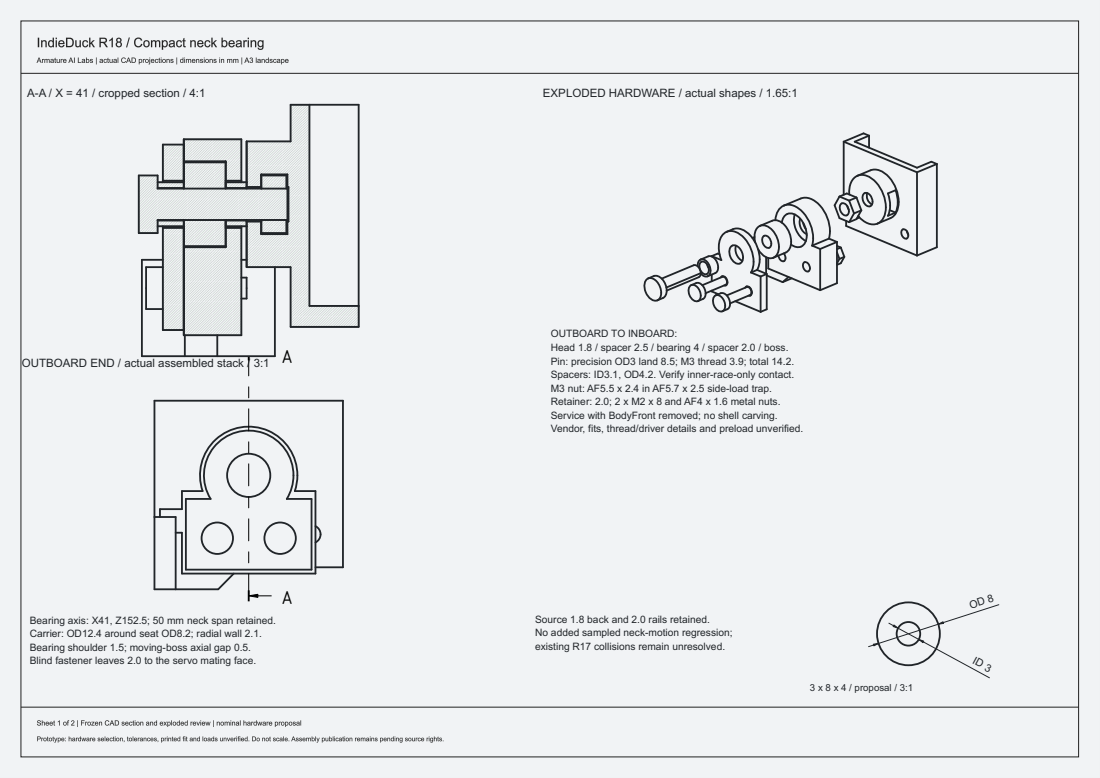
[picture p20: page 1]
A-A / X = 41 / cropped section / 4:1; 3 x 8 x 4 / proposal / 3:1

EXPLODED HARDWARE / actual shapes / 1.65:1

OUTBOARD TO INBOARD:
Head 1.8 / spacer 2.5 / bearing 4 / spacer 2.0 / boss. Pin: precision OD3 land 8.5; M3 thread 3.9; total 14.2. Spacers: ID3.1, OD4.2. Verify inner-race-only contact. M3 nut: AF5.5 x 2.4 in AF5.7 x 2.5 side-load trap. Retainer: 2.0; 2 x M2 x 8 and AF4 x 1.6 metal nuts. Service with BodyFront removed; no shell carving. Vendor, fits, thread/driver details and preload unverified.

OUTBOARD END / actual assembled stack / 3:1

Bearing axis: X41, Z152.5; 50 mm neck span retained. Carrier: OD12.4 around seat OD8.2; radial wall 2.1. Bearing shoulder 1.5; moving-boss axial gap 0.5. Blind fastener leaves 2.0 to the servo mating face.

Source 1.8 back and 2.0 rails retained. No added sampled neck-motion regression;

existing R17 collisions remain unresolved.

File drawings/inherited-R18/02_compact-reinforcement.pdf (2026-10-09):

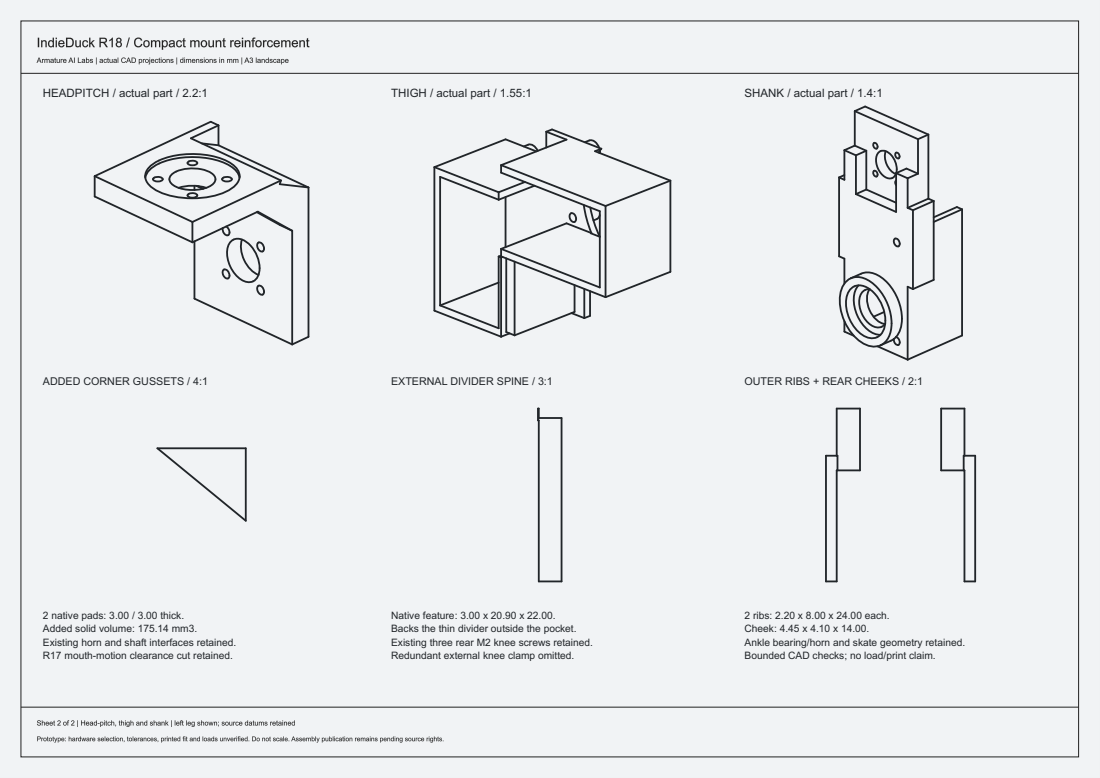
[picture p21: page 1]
HEADPITCH / actual part / 2.2:1; THIGH / actual part / 1.55:1; SHANK / actual part / 1.4:1

ADDED CORNER GUSSETS / 4:1

EXTERNAL DIVIDER SPINE / 3:1

OUTER RIBS + REAR CHEEKS / 2:1

2 native pads: 3.00 / 3.00 thick. Added solid volume: 175.14 mm3. Existing horn and shaft interfaces retained. R17 mouth-motion clearance cut retained.

Native feature: 3.00 x 20.90 x 22.00. Backs the thin divider outside the pocket. Existing three rear M2 knee screws retained. Redundant external knee clamp omitted.

2 ribs: 2.20 x 8.00 x 24.00 each. Cheek: 4.45 x 4.10 x 14.00. Ankle bearing/horn and skate geometry retained. Bounded CAD checks; no load/print claim.

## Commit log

2026-10-09 Publish complete R20 CAD study with integrated removable head band
    [COMPONENTS.csv, IndieDuck_R20_Assembly.FCStd, IndieDuck_R20_Interfaces.FCStd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]
2026-10-09 Add revisioned R20 display assets while preserving mechanical sources
    [A_BodyBack.stl, A_BodyFront.stl, A_HeadPitch.stl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]
2026-10-13 Publish R25 reference-driven exterior as the current CAD design
    R25 adds a tapered helmet, recessed camera face, orange rims and rings,
    faceted torso, hip cowls, thigh, shin and toe caps and faceted feet to the
    unchanged R20 mechanism. R20 remains in the repository and at its tag.
    For publication: swept neck clearance in TorsoFront and the trunk, neck
    link trim; neck clear from -65 to +27.5 degrees. HelmetLower print
    orientation documented (upside down). 51 STEP/STL exports, assembly STEP,
    previews, export readback and fix records. Design-review candidate, not a
    manufacturing release.
2026-10-13 Replace the XGO-derived head base with an IndieDuck-drawn part
    A_HeadBase replaces A_O2_HeadBase (built on XGO head.stl). Drawn from
    IndieDuck parameters: same footprint and mounting points, 5 mm floor,
    stiffening wall, clearances from neighbouring parts and from the swept
    head roll, head yaw and jaw. Clear statically and through roll +-25,
    yaw +-90, jaw 0..30 and neck -65..+27.5 degrees. Prints flat without
    supports. Editable PartDesign source added.
    The R25 robot now contains no XGO-Duck geometry; XGO notices remain
    for the R20 files kept in the repository. Also records the roll-servo
    cradle change between R20 and R25.
2026-10-13 Remove R20 files and XGO-Duck notices from the current branch
    R25 contains no XGO-Duck geometry since r25-cad-study-v2. Remove the R20
    native documents, R20 exports, the R20 display bundle, inherited R18
    drawings, R20 previews and validation records, and the XGO notices that
    only applied to them. R20 and earlier remain available at their tags.
    Update README, CONTRIBUTING, VERIFICATION, previews notes, components,
    manifest and checksums for an R25-only branch.
2026-10-14 Rebuild faceted jaw features as exact geometry
    AngularJaw: bearing-side boss and bore, horn-side screw holes,
    counterbores and centre hole, and the side-plate edges rebuilt as exact
    cylinders (triangular faces 532 to 60, volume within 0.07 %).
    JawSurround_L: four integral pins rebuilt exact (177 to 0). Clearances
    re-checked. Remaining facets recorded in validation/R25-face-cleanup.json.
2026-10-14 Remove an accidental duplicate assembly file
2026-10-14 Remove the last tessellated geometry from R25
    AngularJaw lower plate corners rebuilt exact (6.775 mm arc and flat
    bottom intersected with a 3 mm round along x). Head base rebuilt
    against the clean jaw. No part now contains tessellated geometry;
    HeadRim bevels are deliberate low-poly design faces. Clearances,
    exports and slicing re-checked.
2026-10-14 Add the four support parts missing from the printed list
    Jaw bearing tower, keeper and plug, and neck bearing retainer were modelled
    but absent from COMPONENTS.csv. Exported (STEP valid, 0 ppm drift, STL closed)
    and listed: 55 printed parts. README points to the project BOM.
2026-10-15 Trim covers to clear the verified joint ranges; fix three joint labels
    Camera-carrier screws moved to the head-yaw link and hip-pitch clamp screws and
    nuts to the hip-roll link (inherited labelling errors that jammed head roll and
    hip pitch in sweeps). Pelvis front, hip cowls, toe caps, shin caps and pelvis
    rear trimmed by the swept path of the parts they hit plus 1 mm. All leg joints
    and the neck verified clear in 1 deg steps; ranges recorded. Mouth rim/surround
    interference left as an open design item.
2026-10-15 Organise the CAD as platform P1 plus IndieDuck Cyber Edition
    The current design (R25 exterior by Zankar Savalia) is IndieDuck Cyber Edition.
    platform/ holds the shared mechanism (27 printed parts, P1_* exports, editable
    head base, PLATFORM.md with the rules for editions); editions/cyber/ holds the
    complete assembly, the 28 exterior parts (Cyber_* exports), previews,
    validation and edition.yaml. COMPONENTS.csv gains scope and edition columns.
    Files moved with git mv; R25 tags and records kept.
2026-10-15 Add the edition verifier and the platform joint-chain data
    tools/edition_verify.py checks any edition against the platform: edition.yaml and
    COMPONENTS.csv, platform parts unchanged, every exterior part and its exports,
    standing-pose overlaps, and a sweep of every joint against the verified range.
    platform/P1-kinematics.json holds the joint chain, standing pose and verified
    ranges. Cyber Edition report: 14 joints full range, mouth reduced (known rim and
    jaw surround interference), result ATTENTION. README and PLATFORM.md document it.
2026-10-16 Mouth redesign: round jaw-surround caps and matching rim arcs (D25)
    Jaw surrounds trimmed to round caps of 12 mm radius centred on the jaw pivot (pins and holes unchanged); each head rim gets a 13 mm arc at the pivot. The jaw opens 0 to 30 deg with no contact (checked in 2 deg steps). Surrounds about 20 % smaller, rims 5.6 % smaller. Whole-assembly STEP re-exported: it predated the cover trims and jaw clean-up.
2026-10-16 Cyber Edition verification after the mouth redesign: RESULT PASS
    All 15 joints at their full verified ranges in 2 deg steps, mouth 0 to 30 deg included; paperwork, platform, parts and standing-pose checks pass.
2026-10-16 Print colour accents with their panels (D26)
    Optical rings and torso stripes sit exactly on their panels; each panel and its accents is exported as one multi-colour STEP (exports/multicolour/). COMPONENTS.csv gains print_with; PLATFORM.md rule 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
2026-10-16 Cover fixings: M2 screw posts on the platform, re-drilled covers (D27, D28)
    34 M2 x 8 self-tapping screws into printed posts on the trunk, head base, camera carrier, jaw bearing tower, hip brackets, thighs and shanks; covers re-drilled and unused holes filled; pelvis front hooks behind the torso front; face bezel, head rims, rear bumper and toe caps print with a neighbour (print_with, six multi-colour groups); right shin cap mirrored from the left. Every changed part a valid single solid; exports read back; assembly STEP re-exported. edition_verify.py can now sweep extra (platform) parts via EXTRA.
2026-10-16 Pelvis front screwed to the torso front; drop two posts the neck and right hip cowl hit
    The full sweep with the posts found the neck catching one torso-front post and the right hip cowl catching the pelvis-front post; both removed and their holes filled. The pelvis front now takes two M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
2026-10-16 Cyber Edition verification with the cover fixings: RESULT PASS
    All 15 joints at full verified range in 2 deg steps, with the new platform posts swept as well (EXTRA); paperwork, platform, parts and standing-pose checks pass.
2026-10-16 Re-export the upside-down helmet-lower print file from the current part
2026-10-16 Part versions: a revision for every printed part, a what-to-reprint report, and a check on every push
    tools/part_versions.py fingerprints each part from its STL geometry (volume, area, bounding box, centre of mass), keeps PART-VERSIONS.json and the part_rev column, and builds PARTS-CHANGELOG.md listing for every release which parts to reprint and why. History backfilled from git since R25 (13 Oct); release cyber-edition-v2 recorded (29 parts changed since cyber-edition-v1). The Part versions workflow fails any push where a part changed without a new revision.
2026-10-16 Parts catalog: a code, location and revision for every printed part
    COMPONENTS.csv gains part_code and location; tools/part_versions.py builds PARTS-CATALOG.md (grouped by where each part sits, with colour, prints-with, file links and multi-colour files) and its check now fails on a missing or repeated code.
